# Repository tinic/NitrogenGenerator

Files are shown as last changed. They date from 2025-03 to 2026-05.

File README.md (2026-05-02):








# Nitrogen Generator for Home Brewing

> DIY membrane nitrogen generator for **nitro cold brew coffee**, **nitro stout**, and beverage push-gas service. Extracts **99.5%+ pure N₂** from compressed air. Total build cost **$2,222** — about half the price of commercial alternatives like NitroBev 360 or NitroBrew.

[Completed nitrogen generator inside its stainless-steel enclosure](./images/final_inside.jpg)
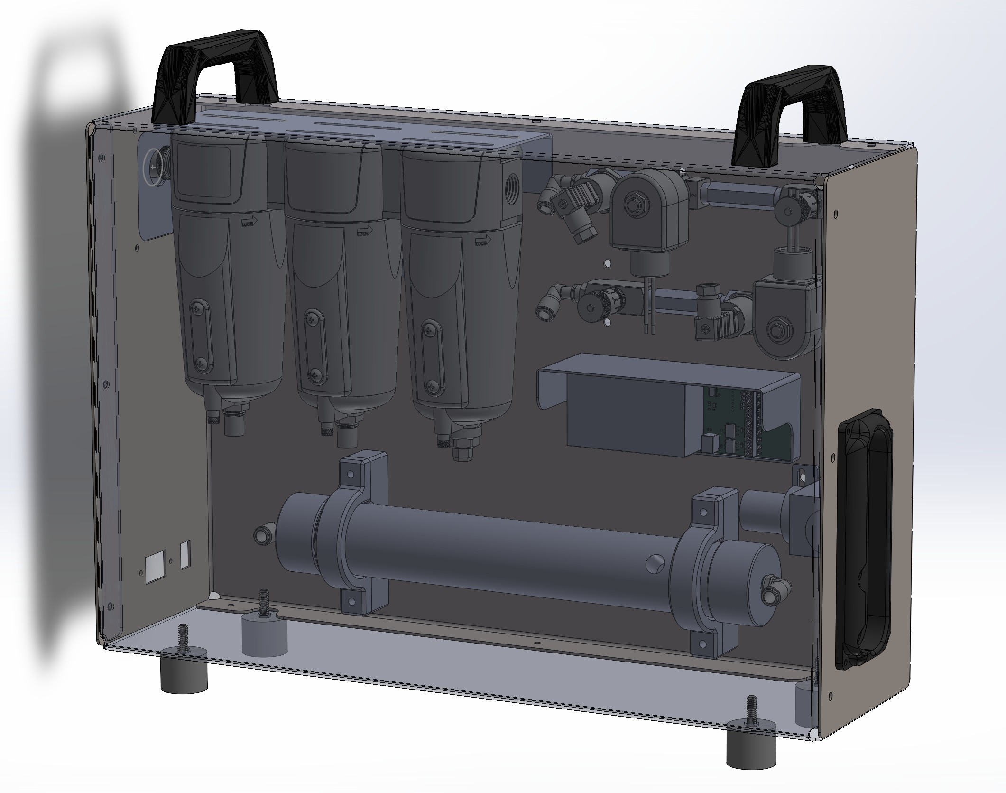
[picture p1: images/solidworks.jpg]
SolidWorks render of the final enclosure design
[](./images/solidworks.jpg)
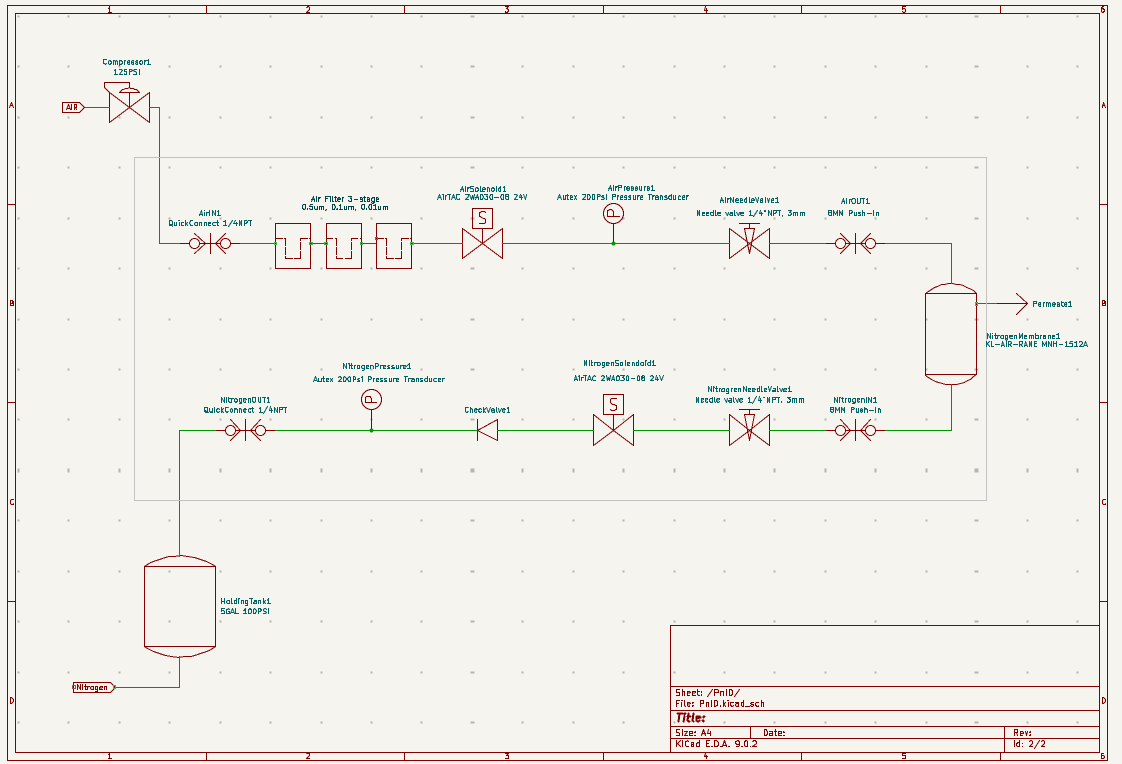
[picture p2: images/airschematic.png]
P&ID-style pneumatic schematic of the system
[](./images/airschematic.png)

## At a glance

| Spec | Value |
|---|---|
| Output flow | 50 L/h (2 CFH) at 100 PSI |
| Output purity | 99.5%+ nitrogen (≤0.5% O₂) |
| Compressed-air input | ≤ 30 L/h (1 CFM) |
| Operating pressure | 75–100 PSI |
| Air-to-N₂ ratio | ~5:1 |
| Power | 120/240 V AC (idle = 0 W; runs only when refilling) |
| Membrane | KL-AIR MNH-1512A |
| Holding tank | 5 gal Cornelius keg |
| Total cost | **$2,222** |

### Cost vs. commercial alternatives

| Option | Cost |
|---|---|
| **This DIY build** | **$2,222** |
| NitroBev 360 | ~$4,500 |
| Industrial PSA nitrogen generator | $8,000+ |

## Motivation

As a home brewer CO₂ is the gas of choice for most purposes, including pushing beverages to the tap. But sometimes you don't want to just serve beer but also cold brew coffee and other non-carbonated beverages. In most cases a simple N₂ cylinder does the job — but given that air is 78% nitrogen, why not just extract it from the air? Recently products like NitroBev 360 have introduced this possibility on a small scale, at a price. Given the huge margins these niche products have to have, my thought was to build a nitrogen generator from scratch for less.

**Use cases this build is sized for:**

- Nitro cold brew coffee on draft
- Nitro stout / Guinness-style cascading head
- Wine and whiskey blanketing during long pours
- Generic beverage push gas where CO₂ would over-carbonate

## How nitrogen generators work

This project uses **membrane separation**. A membrane-based nitrogen generator works by passing compressed air through a semi-permeable membrane made of bundles of hollow polymer fibers. Oxygen and water vapor molecules, being smaller and having a higher permeation rate, pass through the membrane walls and are vented out as permeate. Nitrogen molecules, being larger and slower to permeate, remain inside the fibers and exit at the outlet as a high-purity nitrogen stream. Purity is adjustable down to about 0.5% residual oxygen — well within spec for beverage service.

A membrane generator needs **continuous compressed-air flow** to work. The separation relies on a sustained pressure differential across the fiber walls; if the air supply is intermittent or undersized, the differential collapses and oxygen leaks straight through. The membrane is also engineered for a specific air-flow band — undershoot it and the gas dynamics break down well before you're starving on volume.

A small **needle valve on the membrane output** controls purity. Open it too far and the residence time inside the fiber drops, producing high-O₂ output. Close it too far and most of your compressed air is dumped overboard as permeate, killing efficiency. This adjustment is per-membrane and is the single most important calibration step in the build.

The membrane needs **clean air**. Compressed air carries dust, oil aerosols, water vapor, and hydrocarbons; any of those will foul the polymer fibers. Without proper filtration, a membrane that should last *years* will die in *hours*. We filter down to **0.01 µm** before the air sees the membrane.

### Membrane vs. PSA — why membrane

PSA (Pressure Swing Adsorption) generators reach higher purity (down to a few ppm O₂) but use molecular-sieve beds, twin-tower switching valves, and large compressors — overkill for home use, expensive, and noisy. Membrane is the right scale here: no moving parts, low power, scales down to 50 L/h cleanly, and 99.5% purity is more than enough for beverage service.

## Goals & target metrics

Most commercial large-scale nitrogen equipment is built for continuous N₂ blanketing. We don't need that — a home brewer fills a keg now and then. The design priorities:

- Optimize for **low power** and **casual use**
- **Idle = zero power** (the system only runs when nitrogen is being made)
- Use **readily available, serviceable** components
- **Reasonable N₂ output** for the application — one keg per hour is plenty
- **Portable** — fits in a stainless enclosure, plugs into 120 V
- Reuse equipment home brewers already have (Cornelius keg as accumulator)

Resulting numbers:

- **120/240 V household power** — works on a generator too
- **~50 L/h (2 CFH)** N₂ output — about one keg per hour
- **≤30 L/h (1 CFM)** compressed-air input — small quiet portable compressor is fine
- **100 PSI max** system pressure — Cornelius keg territory

## Skills required

- Hands-on experience with pressurized vessels (kegging-pressure literacy is enough)
- Programming a PLC, Arduino, or microcontroller — the controller is custom firmware here, but ladder logic is fine too
- Comfort with NPT and 8 mm push-in pneumatic fittings, basic leak chasing
- Reading a P&ID
- Multimeter and soldering iron at the level of "I've put together a kit before"

## Bill of materials

These are the actual parts I bought, with what I paid. Substitutes are fine where noted; the membrane and the air filter are the two parts you should not cheap out on.

| # | Component | Model / part | Source | Paid | Notes |
|---|---|---|---|---|---|
| 1 | Nitrogen membrane | [MNH-1512A](./docs/MNH-1512A.pdf) | KL-AIR (Alibaba) | $400 | 50 L/h @ 100 PSI, 99.5%; 120 PSI max input |
| 2 | 3-stage air filter | PneumaticPlus SAFU460-N04-MEP | Amazon | $200 | 0.01 µm coalescing final stage — **don't skimp** |
| 3 | Air compressor | Makita MAC100Q | Hardware store | $250 | Quiet, ~1 CFM, oil-free |
| 4 | O₂ analyzer | FORENSICS O₂ Analyzer | Amazon | $200 | 0–30%, must support flow-through (tube fitting) |
| 5 | Holding tank | 5 gal Cornelius keg | Homebrew supplier | $130 | |
| 6 | Controller | Custom STM32G030 PCB | DigiKey + PCBWay | $130 | $80 BOM + $50 for 5 prototype boards. Click PLC works too (~$300) |
| 7 | Solenoid valves (×2) | AirTAC 2WA030-08 | Amazon | $80 | 24 V DC, normally closed, 1/4″ NPT, Viton seals |
| 8 | Needle valves (×2) | SURUIKE INDUSTRY 3 mm orifice | Amazon | $40 | Stainless, 1/4″ NPT |
| 9 | Pressure transducers (×2) | AUTEX 0–200 PSI | Amazon | $52 | 1/8″-27 NPT, with connector harness |
| 10 | Check valve | Low-cracking-pressure (<2 PSI) | Hardware store | $15 | |
| 11 | Fittings, tubing, cable | Mixed NPT + 8 mm push-in | Hardware store | ~$200 | |
| 12 | Enclosure | Stainless steel, laser-cut + bent | OshCut | $380 | 17-gauge (1.9 mm) — overkill, powder-coated steel halves the price |
| | | | **Total** | **$2,222** | |

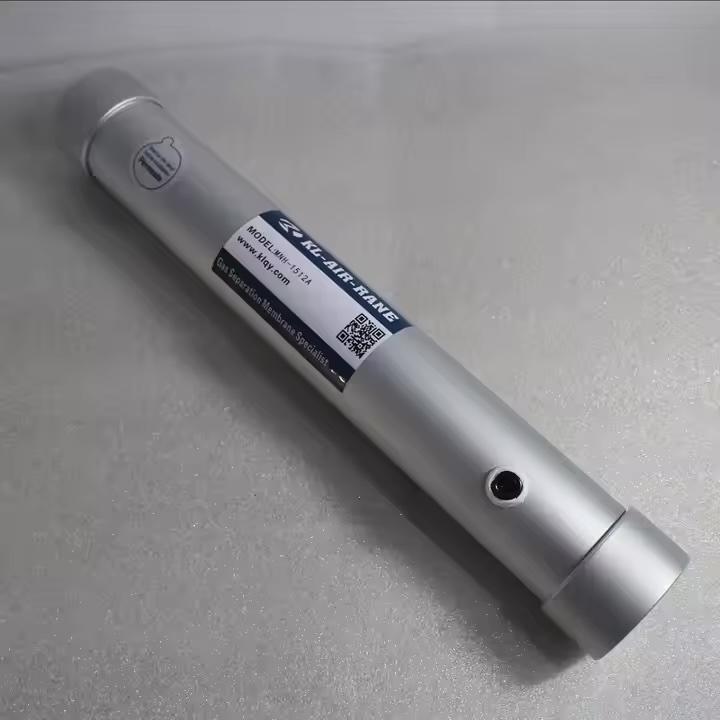
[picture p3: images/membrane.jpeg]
MNH-1512A nitrogen separation membrane
[](./images/membrane.jpeg)
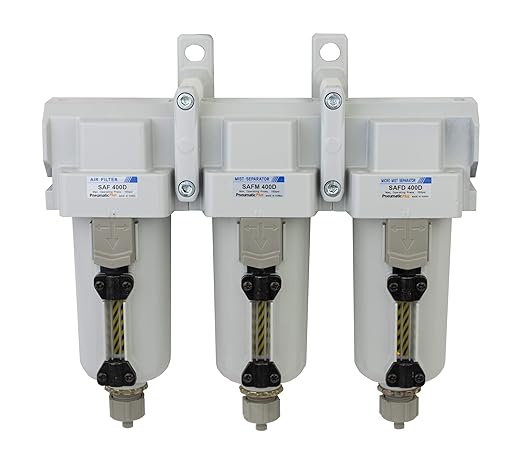
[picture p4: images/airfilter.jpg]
3-stage compressed air filter
[](./images/airfilter.jpg)
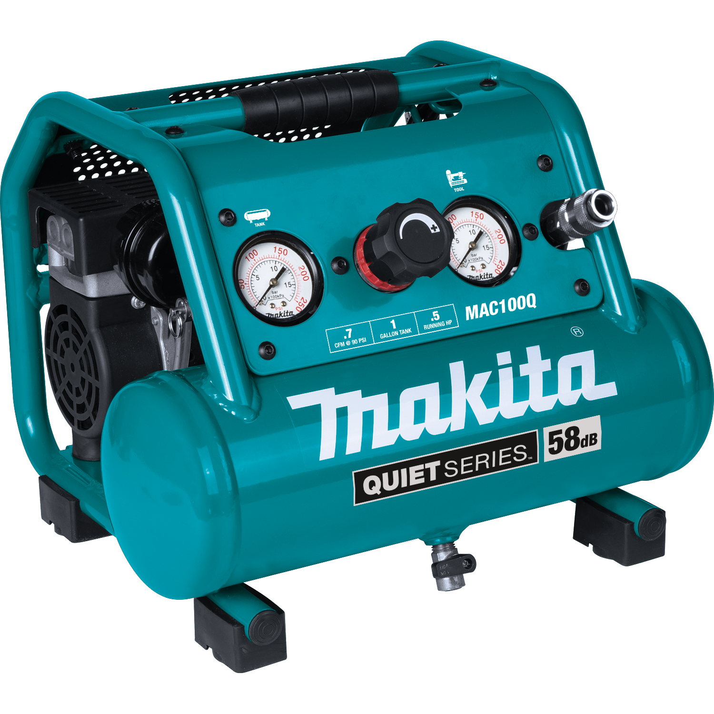
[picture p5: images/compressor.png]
Makita MAC100Q quiet air compressor
[](./images/compressor.png)
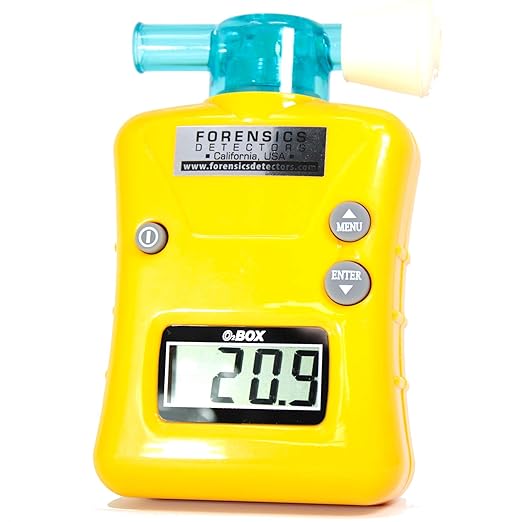
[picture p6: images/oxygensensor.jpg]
FORENSICS oxygen analyzer with flow-through fitting
[](./images/oxygensensor.jpg)
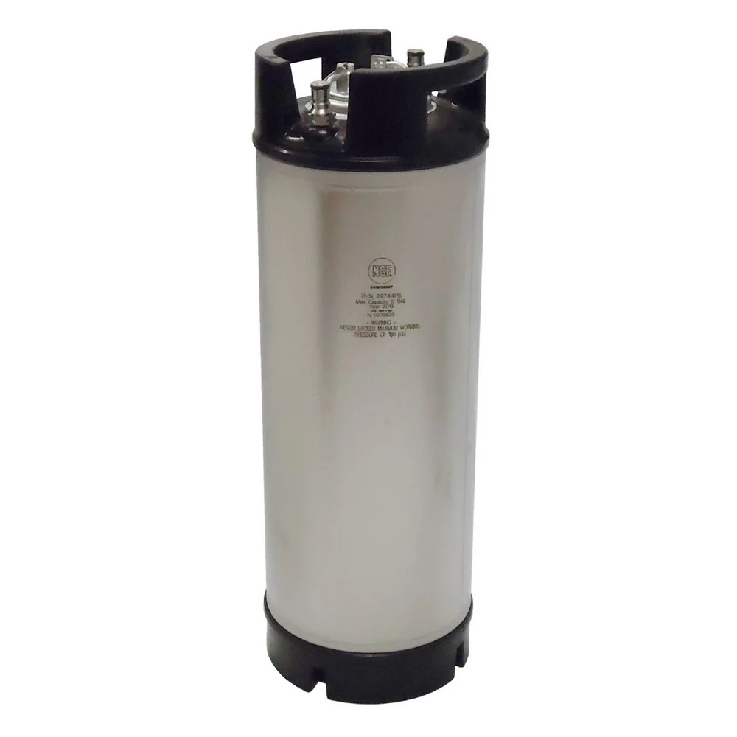
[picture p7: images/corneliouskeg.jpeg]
5-gallon Cornelius keg used as nitrogen accumulator
[](./images/corneliouskeg.jpeg)
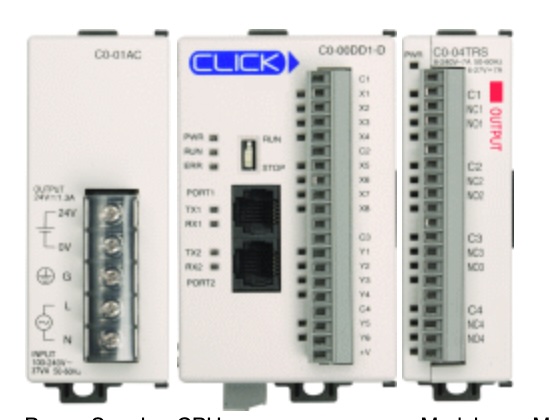
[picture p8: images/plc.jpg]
Click PLC used in the early prototype
[](./images/plc.jpg)
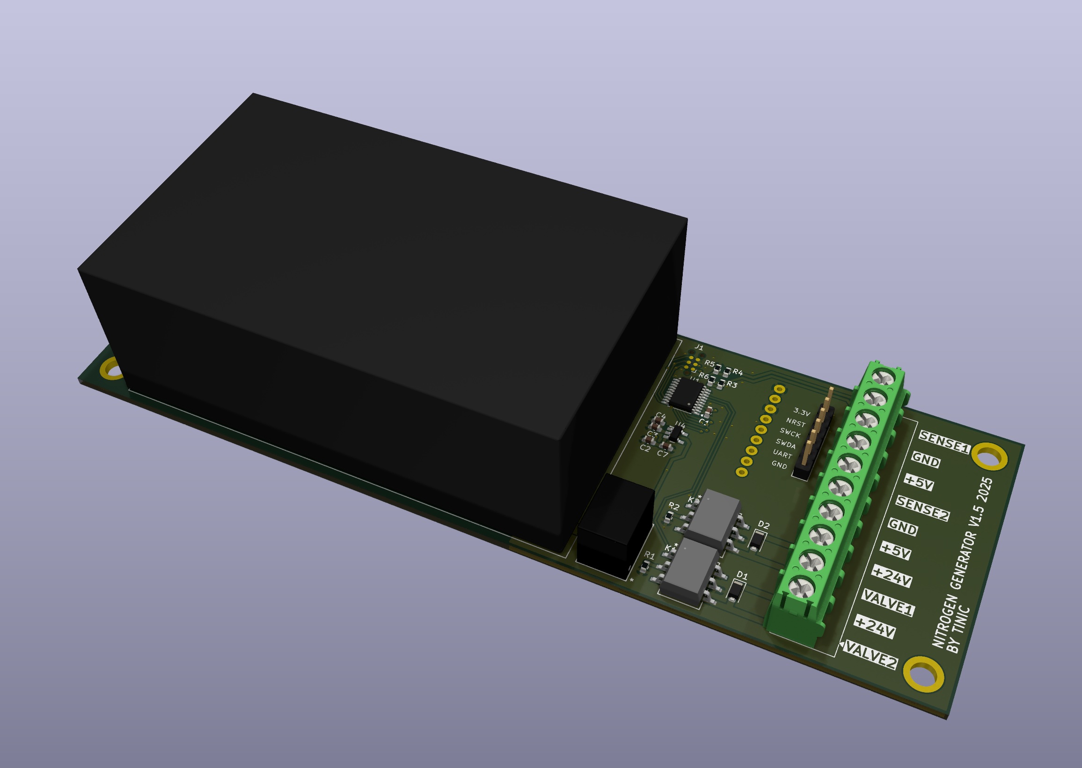
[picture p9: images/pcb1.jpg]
Custom STM32G030 controller PCB, top side
[](./images/pcb1.jpg)
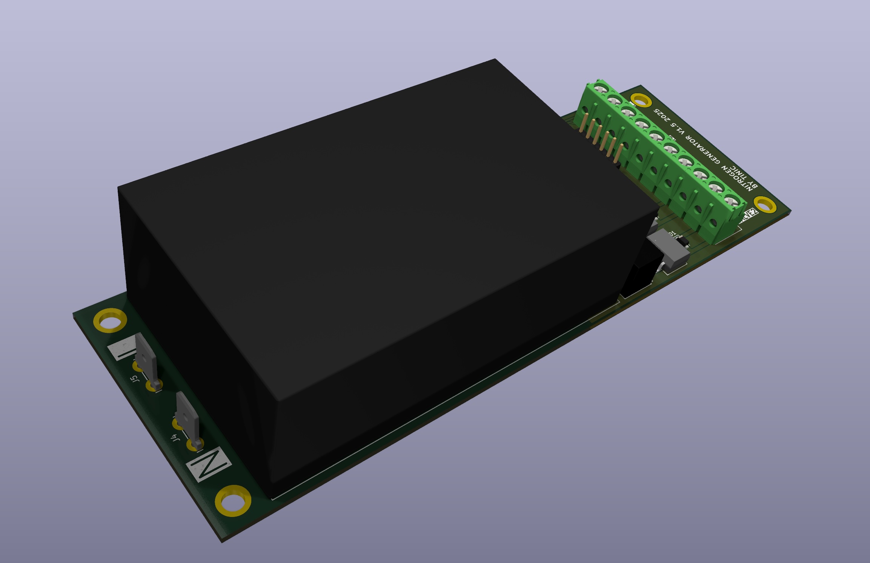
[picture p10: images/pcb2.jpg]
Custom STM32G030 controller PCB, bottom side
[](./images/pcb2.jpg)
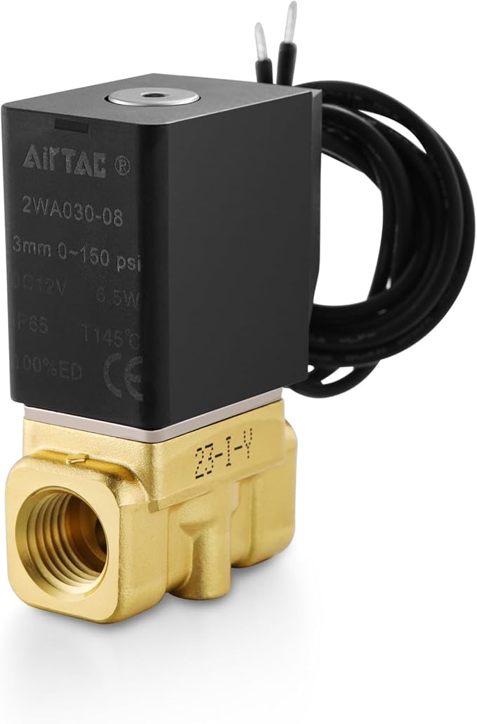
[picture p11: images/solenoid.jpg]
AirTAC 2WA030-08 24V solenoid valve
[](./images/solenoid.jpg)
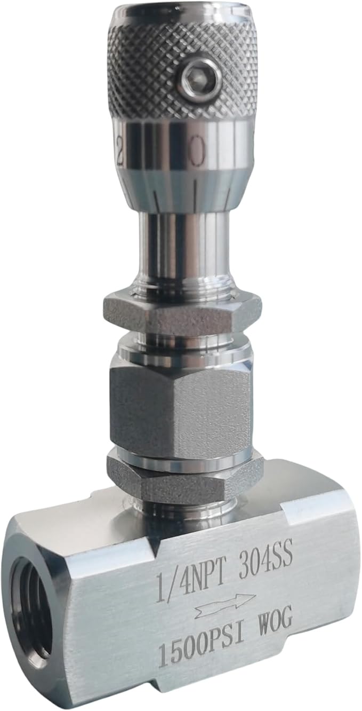
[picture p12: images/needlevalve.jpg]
Stainless steel needle valve, 1/4 inch NPT
[](./images/needlevalve.jpg)
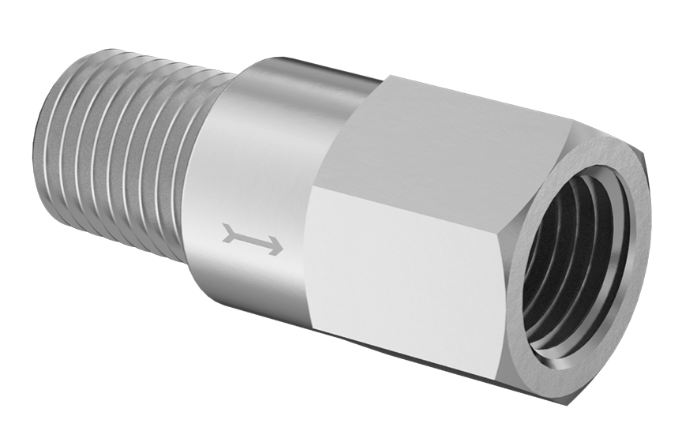
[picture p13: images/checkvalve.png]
Low-cracking-pressure check valve
[](./images/checkvalve.png)
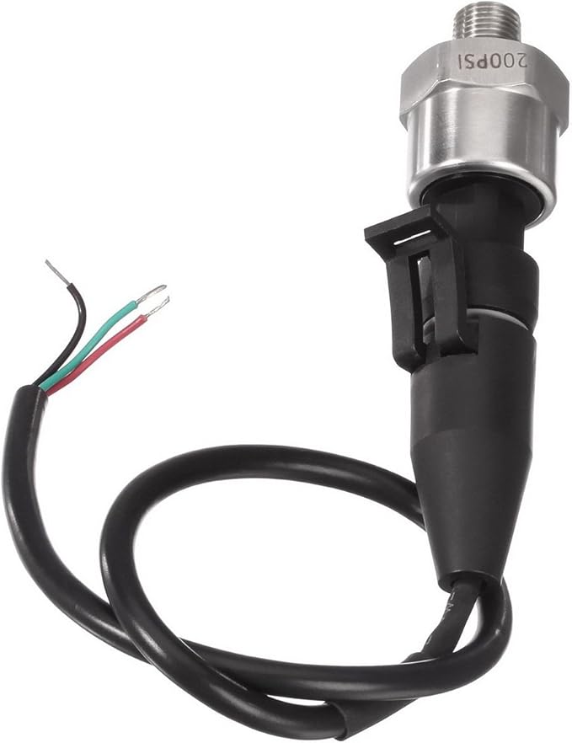
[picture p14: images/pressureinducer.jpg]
AUTEX 0-200 PSI pressure transducer
[](./images/pressureinducer.jpg)

### Don't buy these mistakes

- **Used eBay membranes.** No seller can verify the polymer fibers haven't been clogged with oil or particulates. A fouled membrane looks fine but won't separate. Spend the $400 new.
- **Oversized membranes.** I once snagged an "almost free" deal on a membrane that turned out to need **170 L/min (6 CFM)** of input air. That's an industrial compressor. Read the datasheet's input-flow column before you click buy.
- **Harbor Freight 5 µm filters.** Membrane manufacturers spec **0.01 µm** for a reason. A coarse filter will reduce your membrane lifetime from years to hours. Don't.

## System design

### Pneumatic schematic

[Full P&ID-style pneumatic schematic showing compressor, filter stages, soft-start needle valve, input solenoid, membrane, output needle valve, output solenoid, check valve, accumulator keg, and pressure transducers](./images/airschematic.png)

The KiCad source for the P&ID lives at [`PnID.kicad_sch`](./PnID.kicad_sch).

### Control logic — solenoid sequence

The two solenoids (input air, output nitrogen) gate when air enters the membrane and when nitrogen leaves it. The controller runs this loop:

1. When **NitrogenPressure1** (holding-tank side) drops below **75 PSI**, open **AirSolenoid1** (input) to start filtering.
2. Hold **NitrogenSolenoid1** (output) closed until **AirPressure1** (membrane side) reaches **75 PSI**. This guarantees the membrane is at full operating pressure before any gas hits the keg, so the first nitrogen is at full purity.
3. When **NitrogenPressure1** reaches **100 PSI**, close both solenoids and return to step 1.

Short hysteresis timers (5–10 s) stagger the solenoid transitions to avoid oscillation around the setpoint.

### Safety interlocks

The controller continuously enforces:

- **AirPressure1 < 75 PSI at any point** → both solenoids closed. Prevents back-feed and nitrogen loss from the keg.
- **AirPressure1 > 120 PSI at any point** → both solenoids closed. The membrane's mechanical limit; exceed it and the fibers can shatter.
- **Either pressure < 0 or > 150 PSI** (out of physical range) → both solenoids closed. Fail-safe for sensor failure.

### What the firmware does on every tick

The state machine in [`CubeMX/mcp.cpp`](./CubeMX/mcp.cpp) (function `Slice()`) reduces to:

```
read AirPressure1, NitrogenPressure1
if any sensor out of range:           goto FAULT
if AirPressure1 > 120:                goto FAULT
if AirPressure1 < 75:                 close both solenoids, hold
if NitrogenPressure1 >= 100:          close both solenoids
if NitrogenPressure1 < 75:            open AirSolenoid1 (after 10 s soft-start delay)
if AirPressure1 >= 75:                open NitrogenSolenoid1
update LCD with pressures + state
```

The status LCD is a 192×64 monochrome panel driven via SPI (ST7525) using the [constixel](https://github.com/tinic/constixel) graphics library. UI rendering lives in [`CubeMX/screen.cpp`](./CubeMX/screen.cpp).

## Calibration

Two needle valves to set, in this order: input first (membrane protection), then output (purity).

### Input needle valve — protect the membrane

The input needle valve dampens the pressure step that hits the membrane when the input solenoid suddenly opens. Without it, the membrane sees the full upstream pressure as a step function and the polymer fibers can shatter. **Set this before assembling the rest of the system.**

1. Rig the input needle valve to a regulated air supply.
2. Step the upstream pressure to 100 PSI suddenly.
3. The downstream side should feel like 5–10 PSI bleeding out of a compressor — not a "bang".
4. If you hear a bang, tighten the needle until the step is gentle.

### Output needle valve — set the purity

This sets your final O₂ content. **You need an O₂ analyzer for this step**; eyeballing it is not possible.

1. Set the output needle valve to fully closed during initial leak-testing of the rest of the system.
2. To avoid blasting the analyzer with raw permeate-rich air, open the output valve **only ~4 turns** before any nitrogen flow.
3. Connect the O₂ analyzer directly to the system output via tubing — **no air gaps in the path**, room air contaminating the sample is the #1 calibration mistake.
4. Start the system and slowly close the output needle valve while watching the analyzer. O₂ will start dropping once the membrane has time to flush.
5. Continue patiently — gas takes minutes to flush the analyzer chamber. Make 1/8-turn adjustments and wait 2–5 minutes between them.
6. Stop when you reach **≤ 1% O₂**. Closing further shoots permeate-to-product ratio above ~5:1 with no purity gain.
7. **What success feels like:** at 99.5% purity and 50 L/h, you can barely feel air on your lips at the output. That's normal. If you can clearly feel flow, you're at higher O₂.

Mark the final valve position with a paint pen so you can return to it after maintenance.

## Repository layout

```
.
├── CubeMX/                   STM32G030 firmware (CMake + arm-none-eabi-gcc)
│   ├── mcp.cpp               Control state machine (Slice())
│   ├── screen.cpp            LCD UI rendering (constixel-based)
│   ├── build.sh              One-shot build
│   └── CMakeLists.txt
├── NitrogenGenerator.kicad_*  KiCad PCB project (controller board)
├── PnID.kicad_sch            P&ID schematic of the pneumatic system
├── solidworks/               Mechanical CAD for the stainless enclosure
├── docs/                     Datasheets (membrane, components)
├── images/                   Photos and renders used in this README
├── kicad-makefile/           Production-file generation (gerbers, BOM)
└── pnid-lib/                 KiCad symbols for P&ID drawing
```

## Building

### Firmware

```bash
git clone https://github.com/tinic/nitrogengenerator.git
cd nitrogengenerator/CubeMX
./build.sh
```

Requirements:

- [ARM GCC toolchain](https://developer.arm.com/Tools%20and%20Software/GNU%20Toolchain) (`arm-none-eabi-gcc`)
- CMake 3.22+
- Python 3 (for font and image asset conversion)

Flash with your favourite STM32 programmer (ST-Link, Black Magic Probe, etc.) — the build emits a `.elf`, `.bin`, and `.hex` in `CubeMX/build/`.

### PCB

Open `NitrogenGenerator.kicad_pro` in KiCad 7+. Production files (gerbers, drill, BOM) are generated by:

```bash
make -C kicad-makefile
```

Send the resulting zip to PCBWay or any fab. 5 prototype boards came out to ~$50 including shipping at the time of writing.

### Enclosure

`solidworks/` contains the mechanical CAD. The DXF flat patterns in that folder are what I sent to OshCut. Powder-coated steel will halve the cost vs. the 17-gauge stainless I used.

## Reproduction checklist

If you want to build this exact one:

1. Order MNH-1512A from KL-AIR on Alibaba (~$400 + shipping/tariffs).
2. Order PneumaticPlus SAFU460-N04-MEP 3-stage filter (~$200).
3. Get a Makita MAC100Q (or any quiet 1 CFM oil-free compressor).
4. Order 2× AirTAC 2WA030-08 solenoids and 2× SURUIKE 3 mm needle valves (~$120 total).
5. Order the controller PCB from PCBWay using the KiCad files in this repo.
6. Source DigiKey BOM for the PCB (~$80).
7. Order the enclosure from OshCut using `solidworks/` DXFs (or build your own from any rigid material).
8. Flash the firmware: `cd CubeMX && ./build.sh`.
9. Wire per [`PnID.kicad_sch`](./PnID.kicad_sch).
10. Calibrate per the procedure above. Push your first nitro cold brew.

## Safety

- **High-pressure system.** Wear safety glasses while pressurizing. Pressure-test all joints with soap solution before energising electrically.
- **Membrane shock.** Never exceed 120 PSI on the membrane input — the soft-start needle valve is what protects you. Don't ever bypass it.
- **Asphyxiation hazard.** N₂ at 99.5% will displace breathable oxygen in a small enclosed space. Keep the area ventilated. The output stream is small (50 L/h), but a leak in a closet matters.
- **Electrical.** 24 V DC is present at the solenoid driver outputs. Use an IP-rated enclosure if the unit lives anywhere humid (kegerators, garages).
- **Pressure relief.** Install a relief valve set to 110 PSI between the membrane output and the keg, in case the output solenoid fails closed and the input doesn't shut off.

## Troubleshooting

| Problem | Symptoms | Likely cause | Fix |
|---|---|---|---|
| No N₂ flow | Tank pressure stays flat | Output valve too closed; membrane fouled; control fault | Open output 1/4 turn; check filter element; check sensor readings on LCD |
| O₂ reading > 2% | Analyzer never drops below 2% | Output valve too open; membrane degraded; air gap in sample line | Close output 1/8 turn; verify no leaks in analyzer hose; if problem persists with new tubing, suspect membrane end-of-life |
| Flow rate < 40 L/h | Slow keg fill | Filter element clogged; output valve too closed; input pressure low | Replace filter element; open output slightly; check compressor duty |
| Compressor short-cycles | Compressor kicks on every few seconds | Check valve cracking pressure too high or leaking | Replace check valve with one that opens below 2 PSI |
| Initial high O₂ on startup | Analyzer reads room air for the first few minutes | Normal — gas needs to flush analyzer chamber | Wait 2–5 minutes after first start before adjusting |
| LCD blank but solenoids click | Display SPI fault | Loose ribbon cable; constixel bug | Reseat the LCD connector; reflash firmware |

## Maintenance

| Interval | Task |
|---|---|
| Weekly (in active use) | Drain water from filter bowls; verify O₂ reading on a test pull |
| Monthly | Visual leak check; tighten compression fittings if any have shifted |
| Quarterly | Replace 0.01 µm coalescing filter element; inspect tubing for kinks |
| Annually | Calibrate pressure transducers against a known gauge; full system pressure test |

## FAQ

<details>
<summary><b>Can I just use a CO₂ cylinder instead?</b></summary>

CO₂ is the wrong gas for nitro. The cascading creamy mouthfeel comes from N₂'s low solubility in water — CO₂ over-carbonates and changes the taste. For stout faucets and nitro cold brew you need nitrogen (or a 75/25 N₂/CO₂ blend for some stouts).
</details>

<details>
<summary><b>How long does the membrane last?</b></summary>

**Years** with proper 0.01 µm pre-filtration and clean dry air. **Hours** if the filter element fails or you let oil aerosols through. The filter is the single biggest determinant of membrane lifetime.
</details>

<details>
<summary><b>What's the difference between nitro coffee gas and stout gas?</b></summary>

Nitro cold brew uses ~100% N₂. Traditional Guinness-style stout faucets use a 75/25 N₂/CO₂ blend ("Beer Gas") because the small CO₂ fraction keeps a bit of carbonation in the beer. This generator produces 99.5%+ N₂; for stout-blend service you'd add a CO₂ cylinder and a blender.
</details>

<details>
<summary><b>Do I need a stout faucet?</b></summary>

Yes — a stout faucet has a restrictor plate that breaks dissolved nitrogen out of solution as the beverage passes, which is what creates the cascading head. A standard tap won't produce the effect.
</details>

<details>
<summary><b>Is this safe to run in a small room?</b></summary>

The output flow (50 L/h) is small enough that a normally ventilated room is fine. **Don't** run it in a sealed closet, walk-in cooler, or fermentation chamber without a vent — N₂ is an asphyxiant at high concentrations and you won't notice it before you're hypoxic.
</details>

<details>
<summary><b>Why a custom PCB instead of a Click PLC or Arduino?</b></summary>

The PLC works fine — my first prototype used one — but it's bulky, uses ladder logic, and the BOM is ~$300. The custom STM32G030 board is $130 in parts and parts-on-board, fits in the same enclosure as the pneumatics, and drives the LCD directly. An Arduino would also work at similar BOM cost.
</details>

<details>
<summary><b>Can I scale this up?</b></summary>

Yes — the MNH-2024A membrane outputs ~120 L/h with a proportionally larger compressor (~170 L/h input). Same control logic, bigger plumbing, bigger compressor (which kills the "quiet portable" goal — at that scale you're better off with PSA).
</details>

## Related

- KL-AIR membranes: [alibaba.com](https://www.alibaba.com/) — search "MNH-1512A"
- PneumaticPlus filters: [PneumaticPlus.com](https://pneumaticplus.com/)
- OshCut laser cutting: [oshcut.com](https://www.oshcut.com/)
- PCBWay: [pcbway.com](https://www.pcbway.com/)
- constixel graphics library: [github.com/tinic/constixel](https://github.com/tinic/constixel)

## License

This project is released under [The Unlicense](./LICENSE) — public-domain dedication. Use any part of it for any purpose, commercial or private. **No warranty, no liability.** If you blow yourself up with a misconfigured nitrogen system, that is on you, not me.

---

<sub>If you build one, tag your photos with **#DIYNitrogenGenerator** so others can find it. Pull requests with improvements, alternative BOMs, or photos of working builds welcome.</sub>

<!-- keywords: DIY nitrogen generator, home brewing nitrogen, membrane nitrogen separator, nitro cold brew at home, nitro coffee maker DIY, nitrogen for cold brew, nitro stout home, nitrogen generator from air, MNH-1512A, KL-AIR nitrogen membrane, PneumaticPlus SAFU460, NitroBev 360 alternative, NitroBrew DIY, PSA vs membrane nitrogen, nitrogen on draft, beverage push gas, Cornelius keg nitrogen, stout faucet nitrogen, STM32G030 controller, oxygen analyzer calibration, hollow fiber membrane, nitrogen purity 99.5%, compressed air filter 0.01 micron, oil-free compressor nitrogen, soft start needle valve, asphyxiation safety, beer gas blend, KiCad PCB project, open hardware nitrogen, brewing automation -->

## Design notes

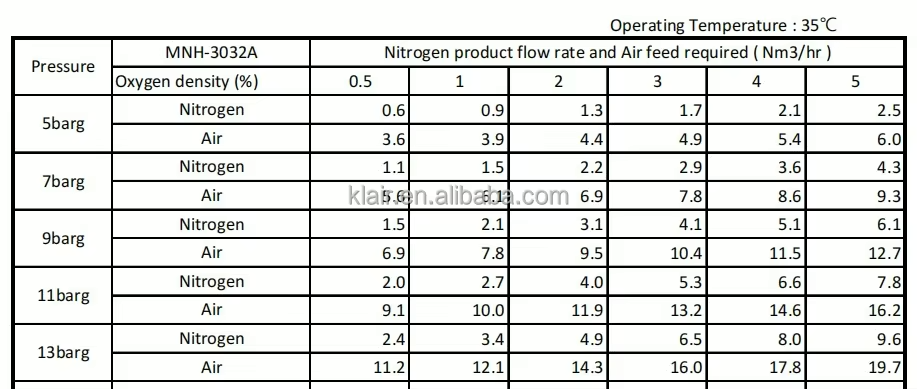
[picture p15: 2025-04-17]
docs/MNH-3032A.png

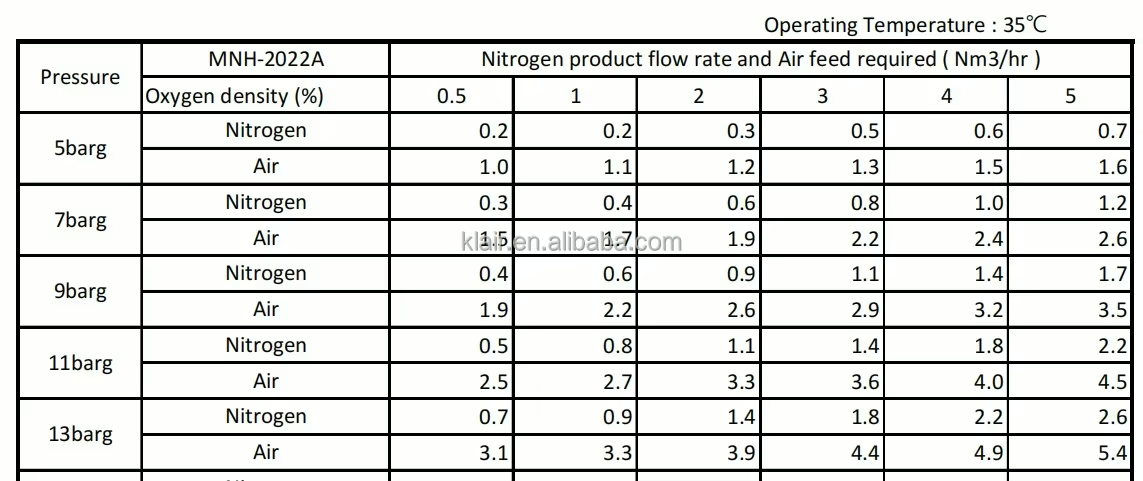
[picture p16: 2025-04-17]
docs/MNH-2022A.png

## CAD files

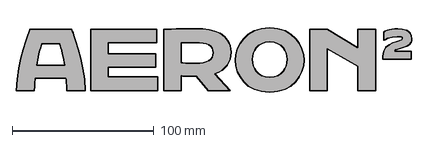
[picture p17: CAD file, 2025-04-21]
media/aeron2.dxf
279.5 x 45.4 mm

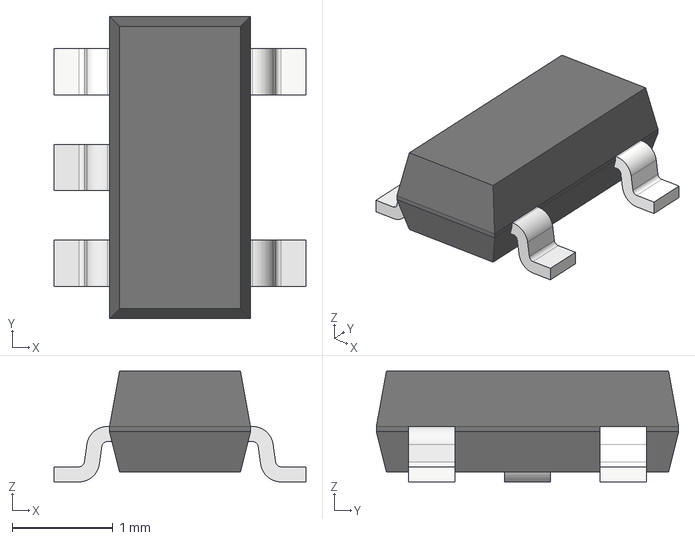
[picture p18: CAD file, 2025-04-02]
NitrogrenGenerator.models/SOT23-5.stp
2.50 x 3.00 x 1.10 mm

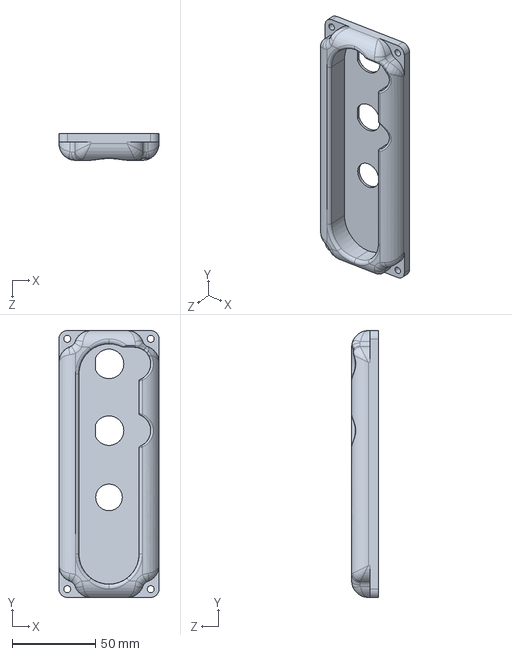
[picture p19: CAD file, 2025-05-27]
solidworks/OuputGuard.SLDPRT
60.0 x 160.0 x 16.0 mm

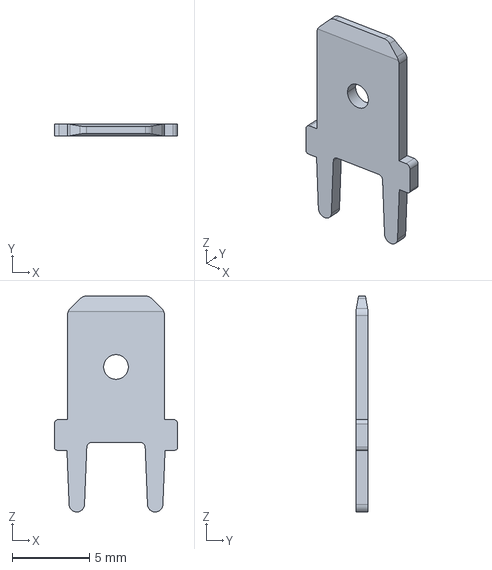
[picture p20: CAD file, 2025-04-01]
NitrogrenGenerator.models/c-726386-2-g-3d.stp
8.00 x 0.8 x 14.0 mm

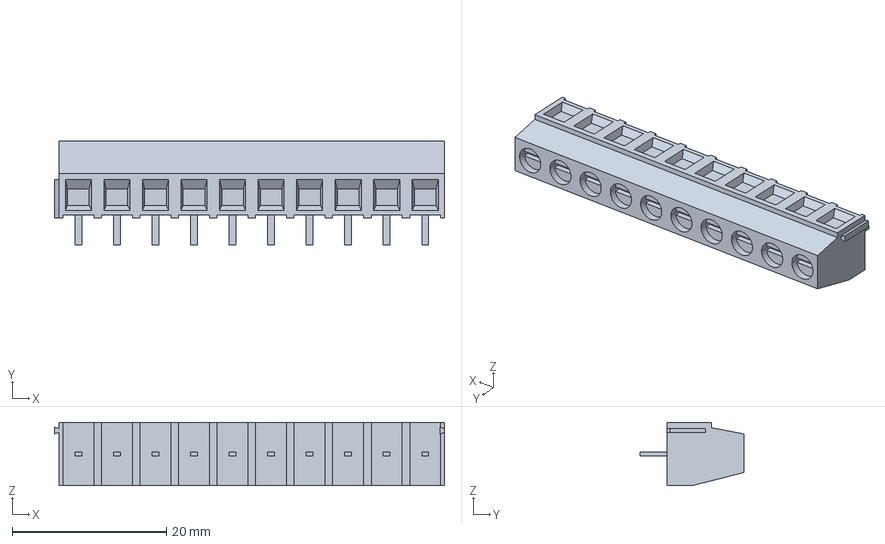
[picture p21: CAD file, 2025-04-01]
NitrogrenGenerator.models/c-1-282836-0-j-3d.stp
50.6 x 13.5 x 8.20 mm

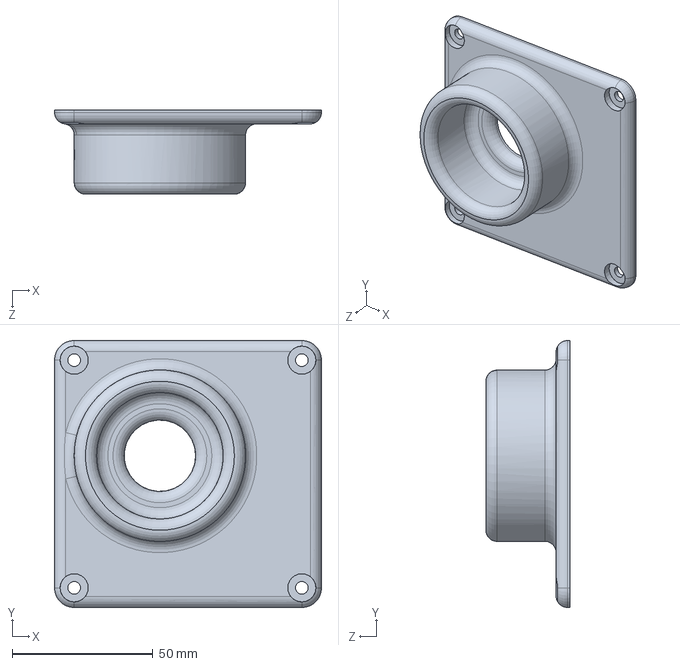
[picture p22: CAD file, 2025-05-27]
solidworks/InputCovert.SLDPRT
95.0 x 95.0 x 30.0 mm

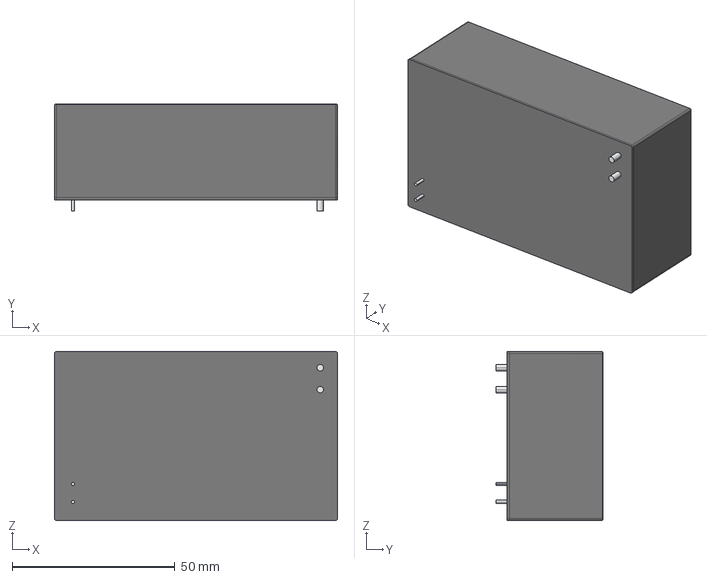
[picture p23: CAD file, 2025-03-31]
NitrogrenGenerator.models/power_supply_irm-45-24.stp
87.0 x 33.0 x 52.0 mm

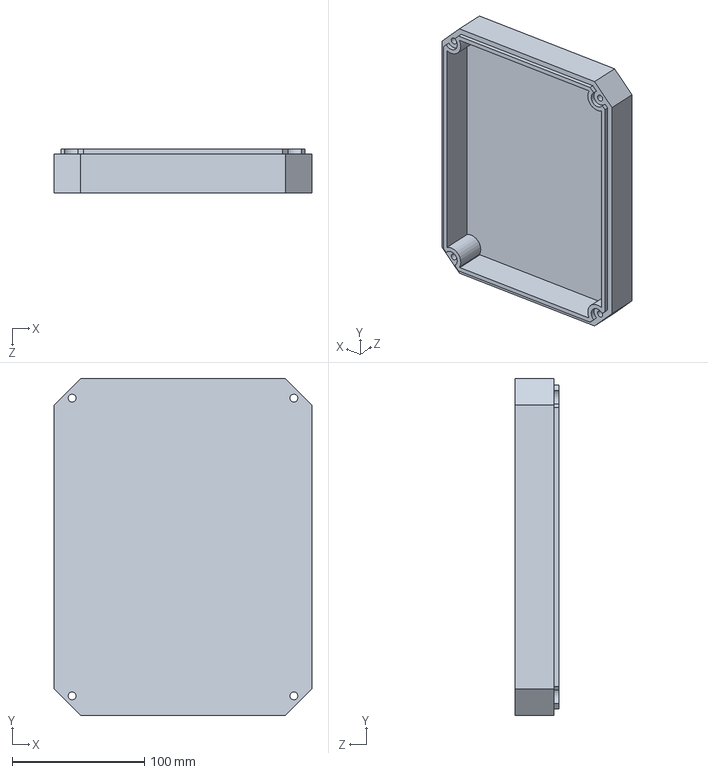
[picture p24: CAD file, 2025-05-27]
solidworks/ControllerBox.SLDPRT
195.0 x 255.0 x 33.4 mm

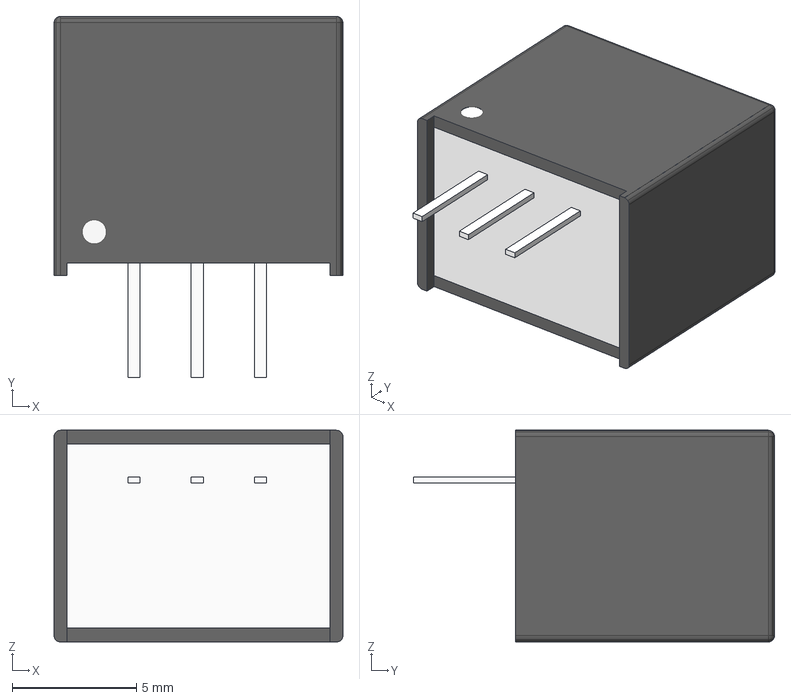
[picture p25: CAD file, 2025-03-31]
NitrogrenGenerator.models/R-78E5.0-0.5.stp
11.6 x 14.5 x 8.51 mm

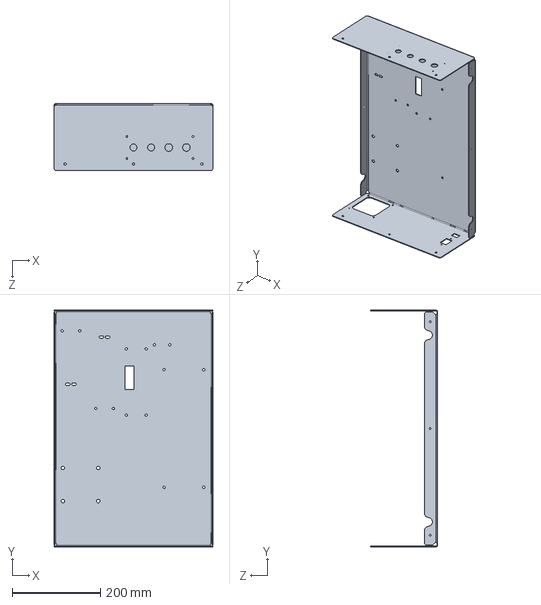
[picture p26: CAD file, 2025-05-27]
solidworks/NitrogenGeneratorCase.SLDPRT
359.8 x 537.2 x 152.4 mm

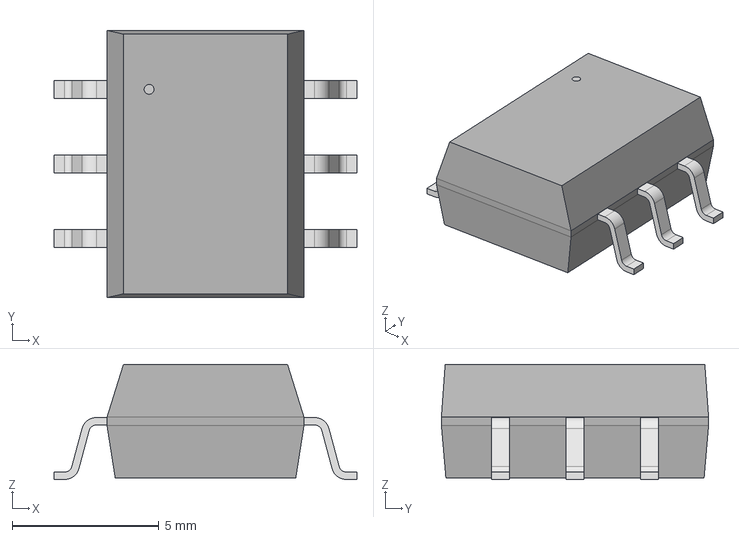
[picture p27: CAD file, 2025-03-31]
NitrogrenGenerator.models/SMD6_AA28F-R1_BTI.step
10.3 x 9.09 x 3.91 mm

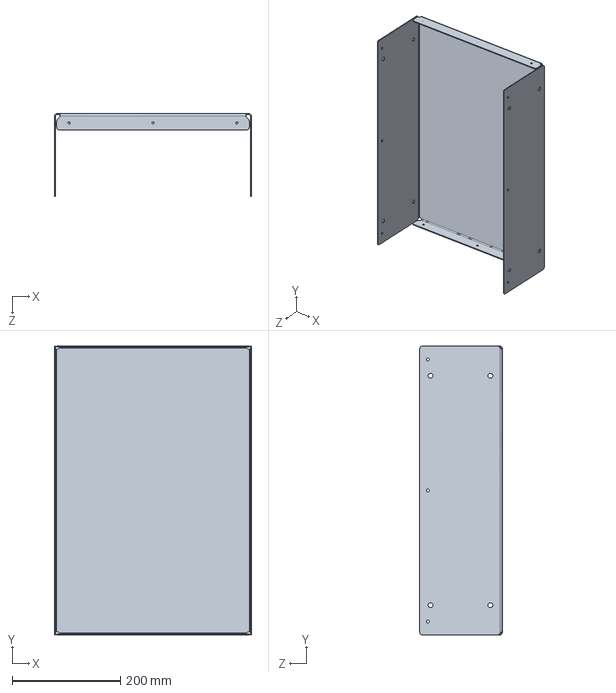
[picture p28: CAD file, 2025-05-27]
solidworks/NitrogenGeneratorCase_Hood.SLDPRT
363.6 x 533.4 x 152.4 mm

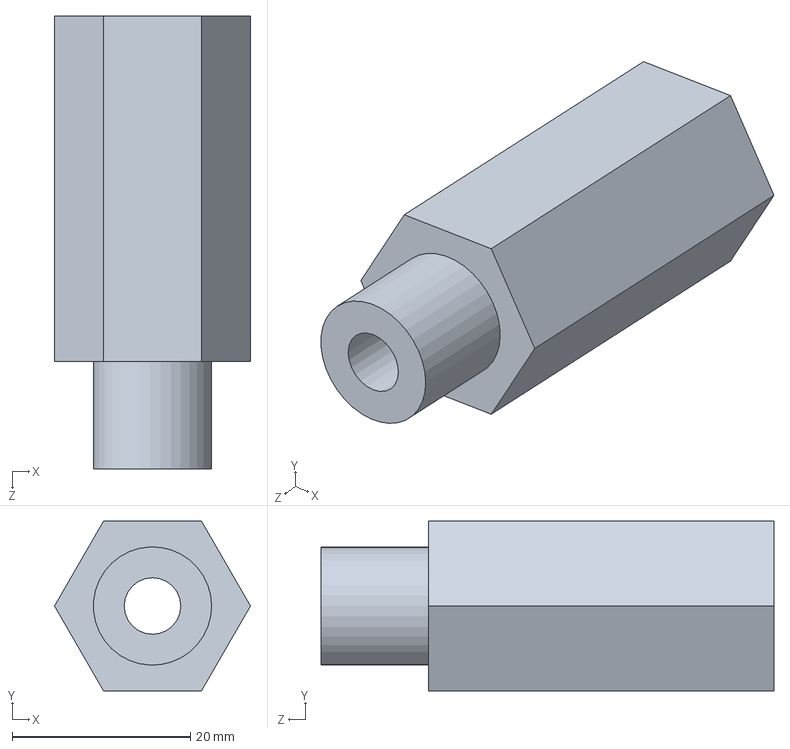
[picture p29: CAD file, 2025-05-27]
solidworks/Tee0.125nptInto0.25.SLDPRT
22.0 x 19.1 x 50.8 mm

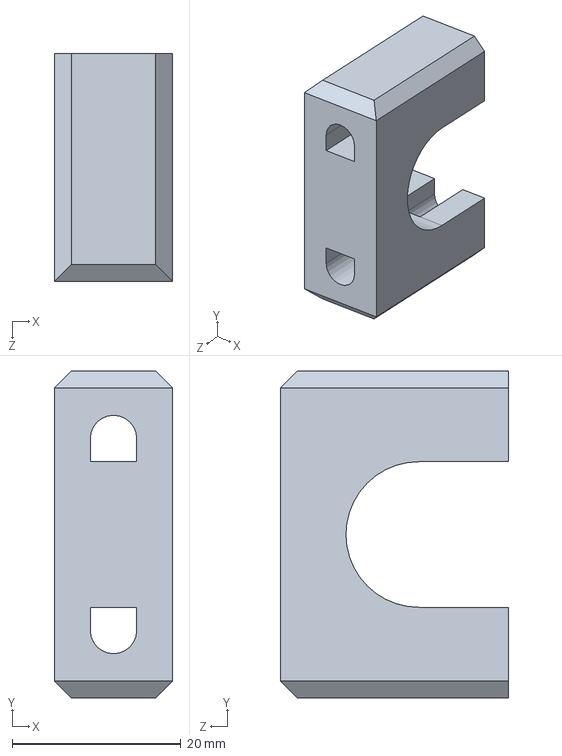
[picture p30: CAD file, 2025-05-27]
solidworks/Clamp2.SLDPRT
14.0 x 38.8 x 27.0 mm

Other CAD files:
solidworks/NitrogenGenerator.SLDASM
solidworks/PneumaticPlusMiniRegulator_Bracket.SLDPRT
solidworks/Clamp.SLDPRT
solidworks/Nipple3in0.25npt.SLDPRT
NitrogrenGenerator.models/TLV70433DBVR.stp
solidworks/1309K13_Compressed Air Filter_Bracket.SLDPRT
solidworks/3196K382_Pressure Transmitter.SLDPRT
solidworks/51305K307_Push-to-Connect Tube Fitting with Universal Thread.SLDPRT
solidworks/5225K119_Push-to-Connect Tube Fitting for Air.SLDPRT
solidworks/5225K725_Push-to-Connect Tube Fitting for Air.SLDPRT
solidworks/6017N15_Economy Pressure Transmitter.SLDPRT
solidworks/6534K46_Industrial Quick-Disconnect Hose Coupling for Air.SLDPRT
solidworks/9546K205_Heavy Duty Threaded-Stud Bumper.SLDPRT
solidworks/IndicatorWasher.SLDPRT
solidworks/LEDStandoff.SLDPRT
solidworks/MNH-1512A.SLDPRT
solidworks/MNH-1512A_Clamp.SLDPRT
solidworks/NitrogenDistributor.SLDPRT
solidworks/PCBStandoff.SLDPRT
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

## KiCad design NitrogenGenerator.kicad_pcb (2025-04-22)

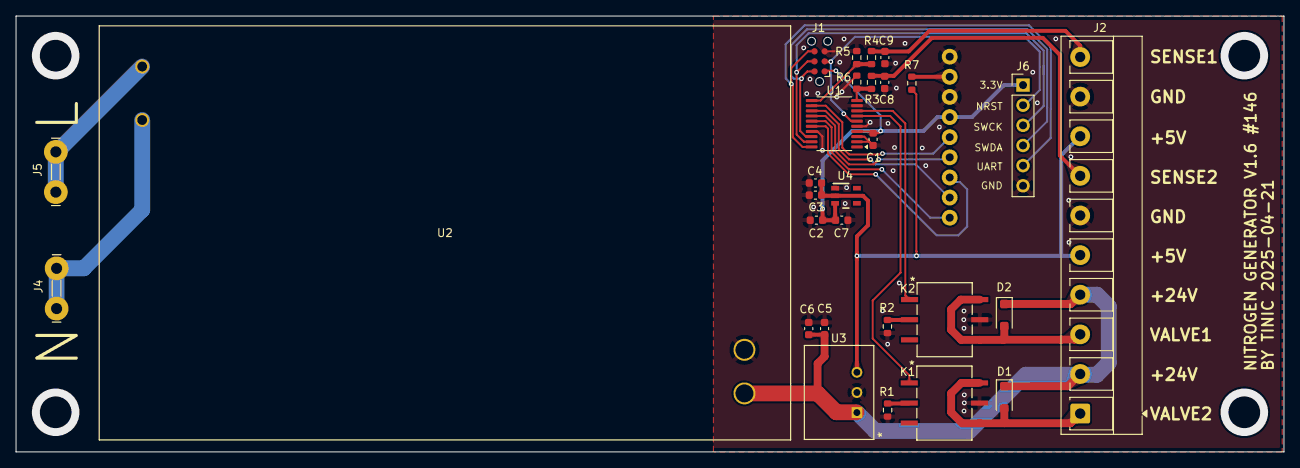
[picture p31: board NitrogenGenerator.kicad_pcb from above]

Board: 2 copper layers, 160.0 x 55.0 mm, 30 parts (1 on the bottom side), 26 nets.

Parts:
C1, C2, C3: 0.1uF; C_0603_1608Metric
C4, C5, C6, C7: 4.7uF; C_0603_1608Metric
C8, C9: 22nF; C_0603_1608Metric
D1, D2: 1N4007; D_SOD-123F
J1: Conn_ARM_SWD_TagConnect_TC2030-NL; Tag-Connect_TC2030-IDC-NL_2x03_P1.27mm_Vertical
J2: Screw_Terminal_01x10; TerminalBlock_RND_205-00284_1x10_P5.00mm_Vertical
J3: ERM19264-4; ERM19264DNS-4
J4, J5: 726386-2; CONN_726386-2_TEC
J6: Conn_01x06_Pin; PinHeader_1x06_P2.54mm_Vertical
K1, K2: AA28F-R1; SMD6_AA28F-R1_BTI
R1, R2: 1.6K; R_0603_1608Metric
R3, R4: 10K; R_0603_1608Metric
R5, R6: 20K; R_0603_1608Metric
R7: 100; R_0603_1608Metric
U1: STM32G030F6Px; TSSOP-20_4.4x6.5mm_P0.65mm
U2: IRM-45-24; IRM-45_MWU
U3: R-78E5.0-0.5; R-78E-0.5_RCP
U4: TLV70433DBVR

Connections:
+3.3V: C1.1, C2.1, C7.1, J1.1 (VCC), J3.4, J6.1, U1.4 (VDD), U4.3 (OUT)
+5V: C3.1, C4.1, J2.5, J2.8, R7.2, U3.3 (+VOUT), U4.2 (IN)
+24V: C5.1, C6.1, D1.1 (K), D2.1 (K), J2.2, J2.4, U2.3 (V+), U3.1 (+VIN)
/CTRL_VALVE_IN: K1.1, U1.7 (PA0)
/CTRL_VALVE_OUT: K2.1, U1.8 (PA1)
/LCD_CD: J3.8, U1.13 (PA6)
/LCD_CS: J3.9, U1.15 (PA8/PB0/PB1/PB2)
/LCD_RESET: J3.7, U1.16 (PA9/PA11)
/LCD_SCK: J3.5, U1.12 (PA5)
/LCD_SDA: J3.6, U1.14 (PA7)
/LOAD_VALVE_IN: D1.2 (A), J2.1, K1.4, K1.6
/LOAD_VALVE_OUT: D2.2 (A), J2.3, K2.4, K2.6
/PRESSURE_INPUT: R3.1, R6.2, U1.10 (PA3)
/PRESSURE_OUTPUT: R4.1, R5.2, U1.11 (PA4)
/SWCLK: J1.4 (SWCLK), J6.3, U1.19 (PA14/PA15)
/SWDIO: J1.2 (SWDIO), J6.4, U1.18 (PA13)
/UART1_TX: J1.6 (SWO), J6.5, U1.20 (PB3/PB4/PB5/PB6)
/~RESET: J1.3 (~RESET), J6.2, U1.6 (NRST)
GND: C1.2, C2.2, C3.2, C4.2, C5.2, C6.2, C7.2, C8.1, C9.1, J1.5 (GND), J2.6, J2.9, J3.1, J3.3, J6.6, K1.5, K2.5, R1.1, R2.1, R5.1, R6.1, U1.2 (PB9/PC14), U1.3 (PC15), U1.5 (VSS), U1.9 (PA2), U1.17 (PA10/PA12), U2.4 (V-), U3.2 (GND), U4.1 (GND)
unnamed: C8.2, J2.7, R3.2
unnamed: C9.2, J2.10, R4.2
unnamed: J3.2, R7.1
unnamed: K1.2, R1.2
unnamed: K2.2, R2.2
unnamed: J5.1, J5.2, U2.1 (AC/L)
unnamed: J4.1, J4.2, U2.2 (AC/N)

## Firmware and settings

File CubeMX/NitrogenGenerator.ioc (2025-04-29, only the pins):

Mcu.UserName=STM32G030F6Px
PA0.GPIO_Label=SOLENOID_VALVE1
PA0.Signal=GPIO_Output
PA1.GPIO_Label=SOLENOID_VAVLE2
PA1.Signal=GPIO_Output
PA13.Signal=SYS_SWDIO
PA14-BOOT0.Signal=SYS_SWCLK
PA3.GPIO_Label=ANALOG_SENSOR1
PA3.Signal=ADC1_IN3
PA4.GPIO_Label=ANALOG_SENSOR2
PA4.Signal=ADC1_IN4
PA5.GPIO_Label=LCD_SCK
PA5.Signal=SPI1_SCK
PA6.GPIO_Label=LCD_CD
PA6.Signal=GPIO_Output
PA7.GPIO_Label=LCD_SDA
PA7.Signal=SPI1_MOSI
PB0.Signal=GPIO_Output

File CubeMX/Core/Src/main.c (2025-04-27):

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
/* Includes ------------------------------------------------------------------*/
#include "main.h"

/* USER CODE BEGIN Includes */
#include <string.h>
#include "../../screen.h"
/* USER CODE END Includes */

ADC_HandleTypeDef hadc1;
DMA_HandleTypeDef hdma_adc1;

SPI_HandleTypeDef hspi1;

TIM_HandleTypeDef htim1;
TIM_HandleTypeDef htim3;

void SystemClock_Config(void);
static void MX_GPIO_Init(void);
static void MX_DMA_Init(void);
static void MX_ADC1_Init(void);
static void MX_SPI1_Init(void);
static void MX_TIM1_Init(void);
static void MX_TIM3_Init(void);
/**
  * @brief  The application entry point.
  * @retval int
  */
int main(void)
{

  /* MCU Configuration--------------------------------------------------------*/

  /* Reset of all peripherals, Initializes the Flash interface and the Systick. */
  HAL_Init();

  /* Configure the system clock */
  SystemClock_Config();

  /* Initialize all configured peripherals */
  MX_GPIO_Init();
  MX_DMA_Init();
  MX_ADC1_Init();
  MX_SPI1_Init();
  MX_TIM1_Init();
  MX_TIM3_Init();
  /* USER CODE BEGIN 2 */
  screen_init();
  HAL_ADCEx_Calibration_Start(&hadc1);
  HAL_TIM_Base_Start_IT(&htim1);
  HAL_TIM_Base_Start_IT(&htim3);
  /* USER CODE END 2 */

  /* Infinite loop */
  /* USER CODE BEGIN WHILE */
  while (1)
  {
    __WFI();
    /* USER CODE END WHILE */

    /* USER CODE BEGIN 3 */
  }
  /* USER CODE END 3 */
}

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


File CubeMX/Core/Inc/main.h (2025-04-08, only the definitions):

#define SOLENOID_VALVE1_Pin GPIO_PIN_0
#define SOLENOID_VALVE1_GPIO_Port GPIOA
#define SOLENOID_VAVLE2_Pin GPIO_PIN_1
#define SOLENOID_VAVLE2_GPIO_Port GPIOA
#define ANALOG_SENSOR1_Pin GPIO_PIN_3
#define ANALOG_SENSOR1_GPIO_Port GPIOA
#define ANALOG_SENSOR2_Pin GPIO_PIN_4
#define ANALOG_SENSOR2_GPIO_Port GPIOA
#define LCD_SCK_Pin GPIO_PIN_5
#define LCD_SCK_GPIO_Port GPIOA
#define LCD_CD_Pin GPIO_PIN_6
#define LCD_CD_GPIO_Port GPIOA
#define LCD_SDA_Pin GPIO_PIN_7
#define LCD_SDA_GPIO_Port GPIOA
#define LCD_RESET_Pin GPIO_PIN_11
#define LCD_RESET_GPIO_Port GPIOA

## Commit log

2026-05-02 README rewrite + Unlicense
    - Restore the original first-person voice + technical reasoning
    (motivation, membrane physics, "don't buy these mistakes" warnings).
    - Concrete BOM with actual receipts ($2,222 total) instead of marketing
    cost ranges; per-component links and photos.
    - New sections: cost vs. NitroBev 360 / PSA, scaling-up FAQ, firmware
    pseudocode (Slice() state machine), repo layout, reproduction
    checklist, troubleshooting matrix, FAQ.
    - Restore the 7-step needle-valve calibration recipe (was inflated to
    18 ceremonial steps in the AI-edited version).
    - SEO: product names (MNH-1512A, PneumaticPlus SAFU460-N04-MEP,
    AirTAC 2WA030-08, Makita MAC100Q), competitor names (Nitro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
2026-05-02 README: badges row (license, last-commit, KiCad, STM32, SolidWorks, Unlicense)
    Carry-forward of the badges added in bf90bea on github/main — that
    commit was on top of the old README, so these need to land fresh on
    top of the rewrite.

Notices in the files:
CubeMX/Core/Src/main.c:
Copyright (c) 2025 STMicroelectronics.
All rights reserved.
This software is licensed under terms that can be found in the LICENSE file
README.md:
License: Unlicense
